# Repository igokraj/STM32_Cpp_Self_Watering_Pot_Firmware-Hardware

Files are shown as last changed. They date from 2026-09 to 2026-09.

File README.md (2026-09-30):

# Self Watering Pot

Projekt zakładał stworzenie automatycznej, samopodlewającej się doniczki na mikrokontrolerze STM32F446RE. Firmware jest napisany w C++. System pilnuje wilgotności gleby i sam włącza pompkę, kiedy gleba robi się za sucha. Da się też wymusić podlewanie ręcznie, a system ma kilka zabezpieczeń na wypadek, gdyby coś poszło nie tak (zaklinowana pompa, uszkodzony czujnik, zawieszony program, pusty pojemnik na wodę).

Do obsługi tego systemu spokojnie można by było użyć mikrokontrolera o mniejszej wydajności, liczbie pinów, pamięci..., jednak ze względu na to, że fizycznie do testowania posiadam jedynie NUCLEO-F446RE, to również na płytce PCB użyłem tego mikrokontrolera dla ujednolicenia projektu. Poniżej zamieszczam zdjęcia prototypu na płytce stykowej (jako zamiennik MOSFETa użyłem diody, symulując jego włączanie/wyłączanie, oraz jako czujnika wilgotności używam ręcznego potencjometru, a do czujnika poziomu wody po prostu kabla, który może być wpięty lub wypięty).

This project set out to build an automatic, self-watering plant pot based on the STM32F446RE microcontroller. The firmware is written in C++. The system keeps an eye on soil moisture and turns the pump on by itself once the soil gets too dry. Watering can also be forced manually, and the system has a few safeguards in case something goes wrong (a stuck pump, a broken sensor, a hung program, an empty water container).

This system would honestly run fine on a much smaller microcontroller which would have a less performance, fewer pins, less memory, but since the only board I physically had for testing was a NUCLEO-F446RE, I used the same chip on the PCB too, just to keep the project consistent. Below are photos of the prototype on a breadboard (I used an LED as a stand-in for the MOSFET, to simulate it switching on/off, a regular potentiometer as a stand-in for the moisture sensor, and for the water level sensor just a loose wire that can be plugged in or pulled out).

## Photos

**Breadboard prototype**
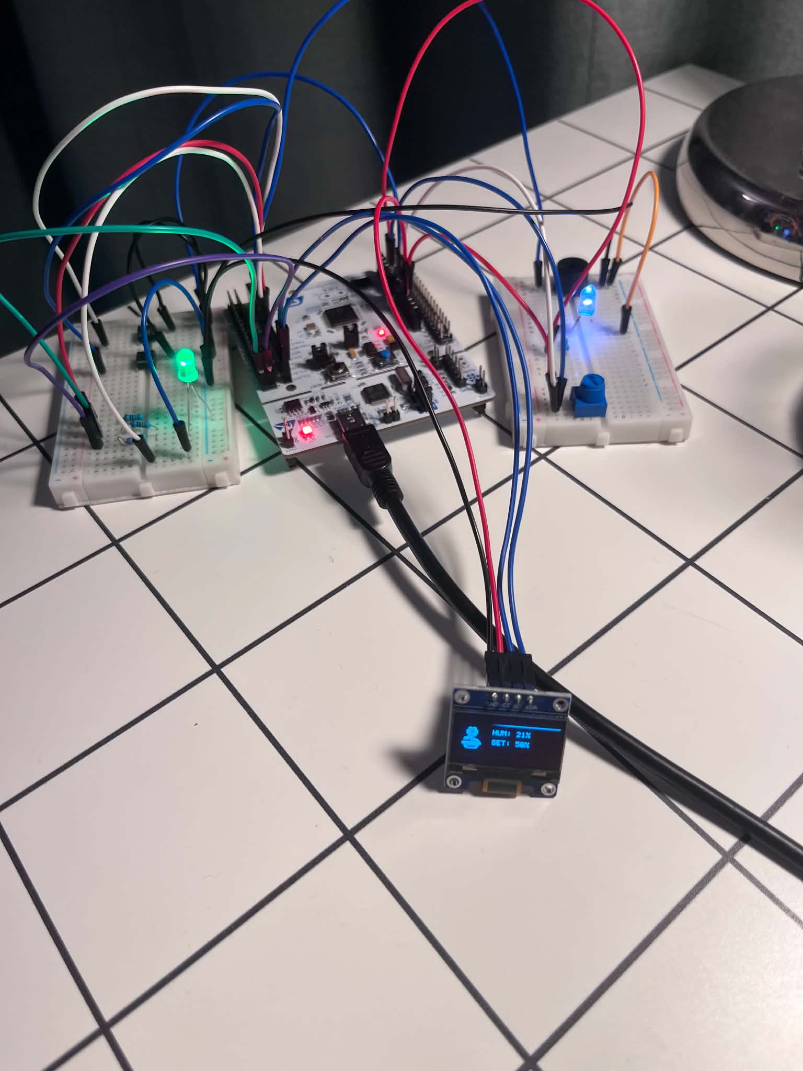
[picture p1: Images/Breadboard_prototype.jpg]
Breadboard prototype


**Schematic**
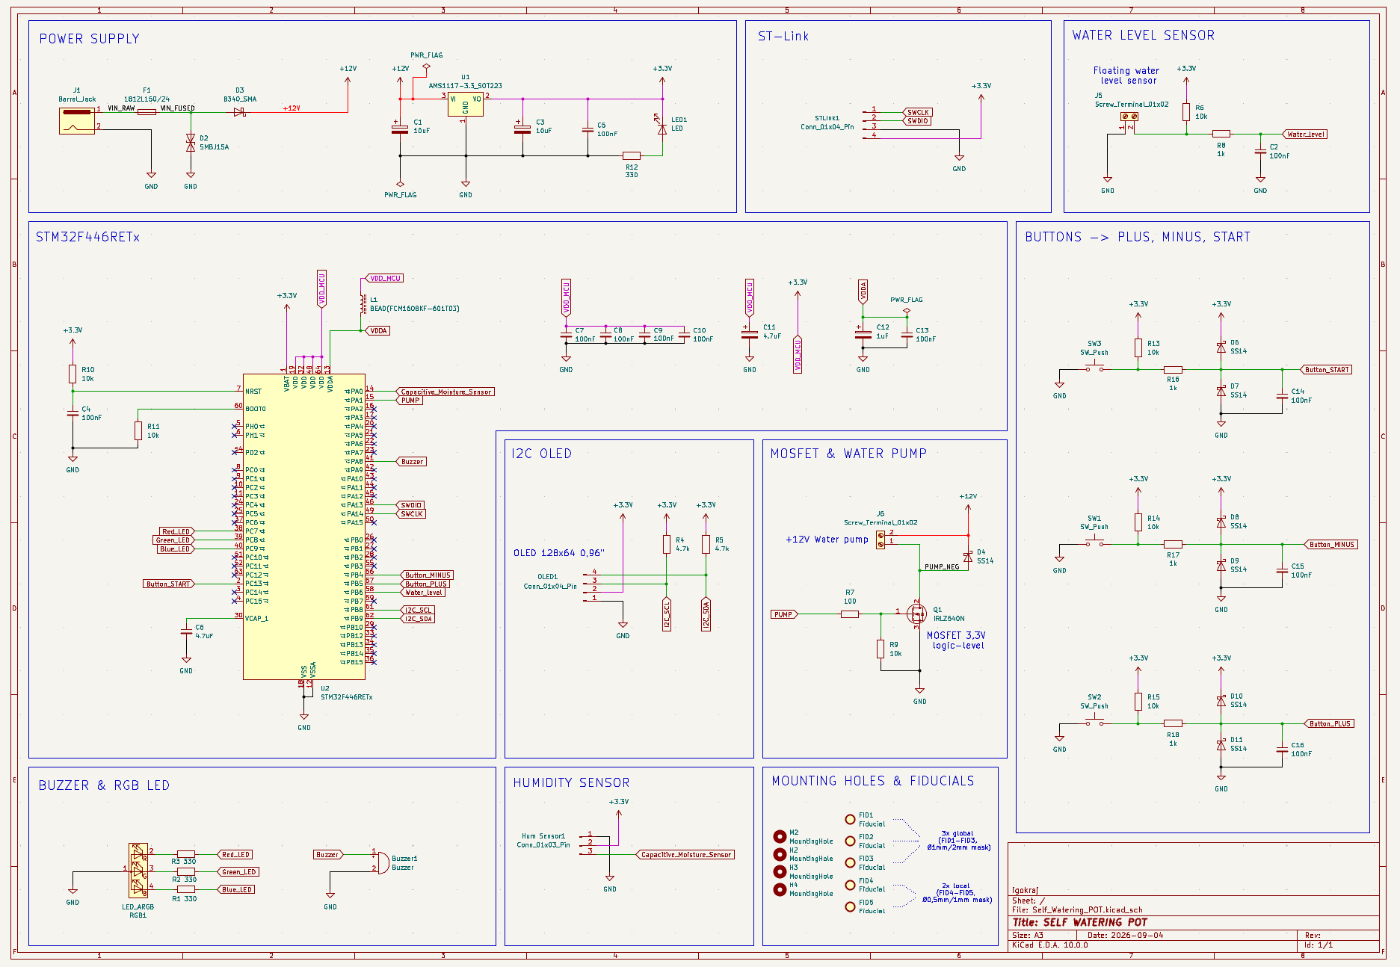
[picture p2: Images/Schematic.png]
Schematic


**PCB layout and 3D render**

<p align="center">
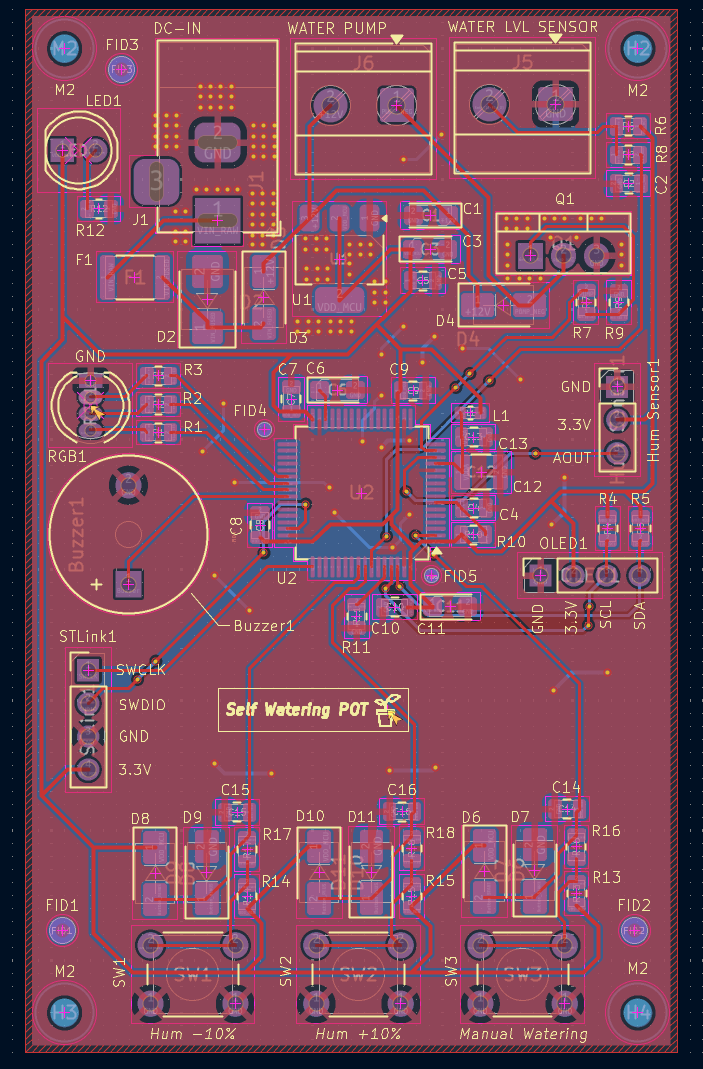
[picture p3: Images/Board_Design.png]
  
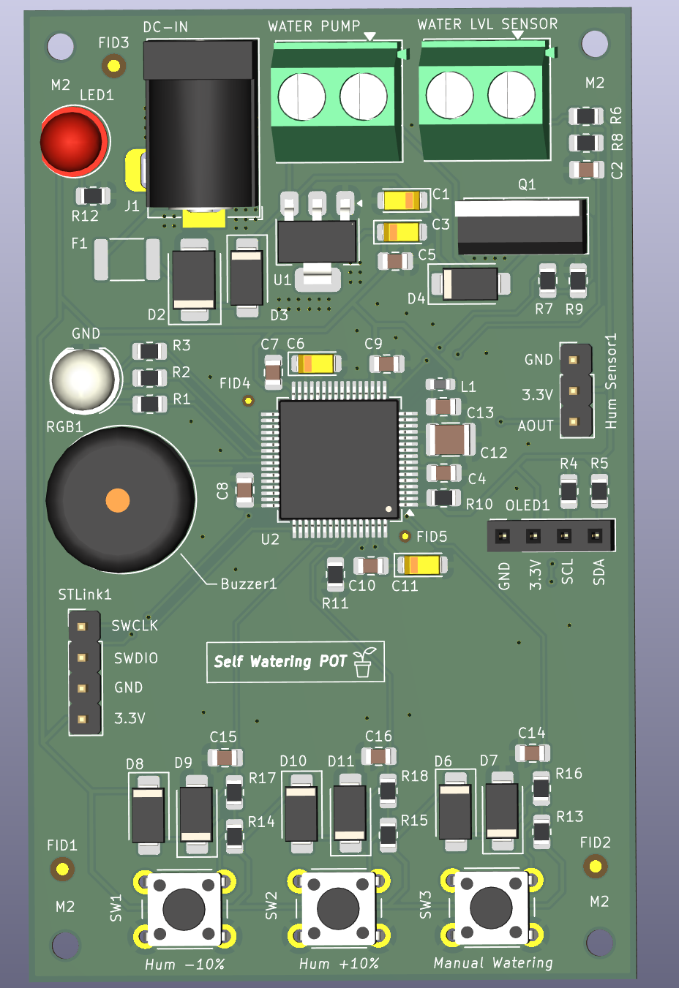
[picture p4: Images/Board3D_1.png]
  
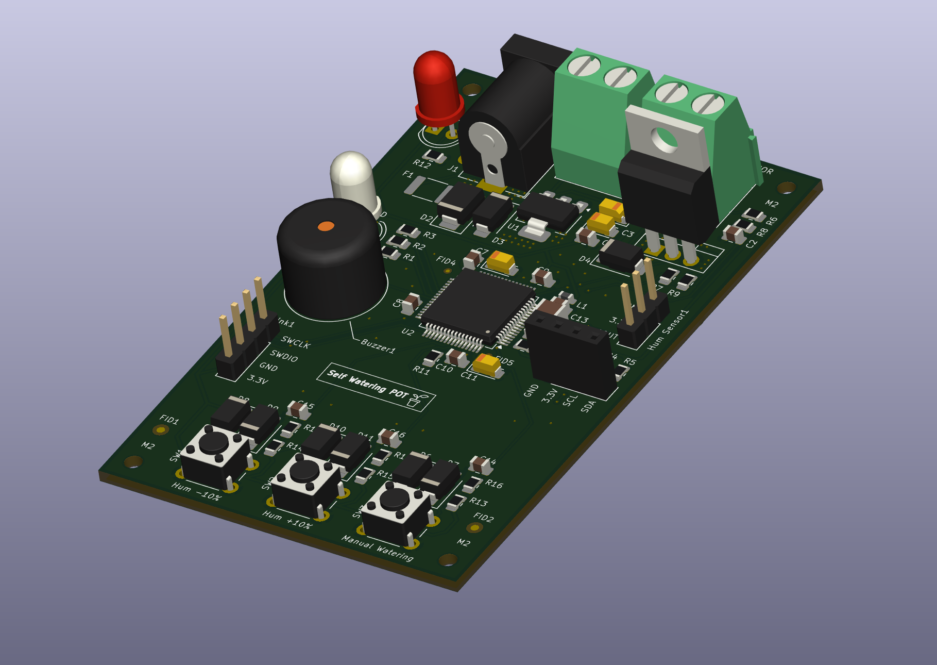
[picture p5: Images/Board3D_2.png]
  
</p>

## How it works

The system has four states: **Waiting**, **Watering**, **EmptyContainer** (no water in the tank), and **Error**.

In the main loop, the program:

1. reads the water level sensor (float switch),
2. handles the Plus/Minus buttons (adjusts the target humidity by 10% per press, with auto-repeat while held) and the manual start button,
3. reads the soil moisture sensor and converts it to a percentage, checking along the way whether the reading looks like a broken/disconnected sensor,
4. decides the state based on that — with priority: pump fault > broken sensor > empty tank > humidity threshold,
5. drives the LEDs, pump, and buzzer, and shows everything on the OLED screen.

Watering kicks in once humidity drops noticeably (by 15 percentage points). If the pump runs continuously for more than 15 seconds, the system treats it as a fault, shuts the pump off for good, and requires a manual reset via the Start button — the buzzer beeps 3 times during this, repeating once a minute.

Holding the Manual Start button forces watering regardless of what the sensor reads.

## Peripherals / electronics

- **STM32F446RETx** — microcontroller
- **Soil moisture sensor** (capacitive) — ADC input
- **Water level sensor** (float switch) — a plain switch
- **3× buttons** — Manual Start, Plus, Minus
- **RGB LED** — indicates system state by color
- **Buzzer** — audible alarm on error
- **Water pump** driven by a MOSFET (IRLZ540N)
- **128×64 OLED display** (SSD1306) over I2C
- **AMS1117-3.3** — 3.3V voltage regulator
- Power connector (barrel jack) with a fuse and overvoltage protection
- SWD connector (ST-Link) for programming/debugging

## BOM (short version)

| Reference | Component | Qty |
| --- | --- | --- |
| U2 | STM32F446RETx | 1 |
| U1 | AMS1117-3.3 (3.3V regulator) | 1 |
| Q1 | IRLZ540N (MOSFET, pump switch) | 1 |
| RGB1 | RGB LED | 1 |
| LED1 | LED (status) | 1 |
| Buzzer1 | Buzzer | 1 |
| SW1–SW3 | Buttons (Start/Plus/Minus) | 3 |
| J1 | Power jack (barrel jack) | 1 |
| J5, J6 | Screw terminals (pump, external power) | 2 |
| Hum Sensor1 | Moisture sensor connector | 1 |
| OLED1 | OLED display connector | 1 |
| STLink1 | Programmer connector | 1 |
| F1 | Fuse | 1 |
| D2 | TVS diode (overvoltage protection) | 1 |
| D3, D4, D6–D11  | Schottky diodes | 8 |
| L1 | Ferrite bead (power filtering) | 1 |
| R, C | Resistors and capacitors (filtering, pull-up/down, debounce circuits) | ~30 |

The full list (with LCSC part numbers) is in `hardware/Self_Watering_POT/BOM.xlsx` and `All_BOM.xlsx`.

## Firmware

The code is written in **C++** (built on top of the C code generated by STM32CubeMX/HAL). The pot's state logic, debounced button handling, OLED display, and buzzer are written as separate classes/modules — the rest (ADC, timer, GPIO, watchdog) is the generated HAL layer.

## Repo structure

- `firmware/` — CMake project with the STM32 sources
- `hardware/` — KiCad schematic and PCB, production files (Gerbers), BOM
- `Images/` — project photos and renders

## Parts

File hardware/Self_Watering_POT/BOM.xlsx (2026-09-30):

Reference | Qty | Value | MPN | Footprint
C1 | 1 | 10uF 25V | C2158829 | Capacitor_Tantalum_SMD:CP_EIA-3216-18_Kemet-A
C3 | 1 | 10uF | C7171 | Capacitor_Tantalum_SMD:CP_EIA-3216-18_Kemet-A
C2,C4,C5,C7,C8,C9,C10,C13,C14,C15,C16 | 11 | 100nF | C49678 | Capacitor_SMD:C_0805_2012Metric
C6,C11 | 2 | 4.7uF | C11369 | Capacitor_Tantalum_SMD:CP_EIA-3216-18_Kemet-A
C12 | 1 | 1uF | C382212 | Capacitor_SMD:C_1210_3225Metric
D2 | 1 | SMBJ15A | C83846 (https://www.lcsc.com/product-detail/C83846.html?s_z=n_q_SMBJ15A) | Diode_SMD:D_SMB
D3 | 1 | B340_SMA | C64982 | Diode_SMD:D_SMA
D4,D6,D7,D8,D9,D10,D11 | 7 | SS14 | C2480 | Diode_SMD:D_SMA
F1 | 1 | 1812L150/24 | C49318453 | Fuse:Fuse_1812_4532Metric
L1 | 1 | BEAD(FCM1608KF-601T03) | C141723 | Inductor_SMD:L_0603_1608Metric
R1,R2,R3,R12 | 4 | 330 | C17630 | Resistor_SMD:R_0805_2012Metric
R4,R5 | 2 | 4.7k | C17673 | Resistor_SMD:R_0805_2012Metric
R6,R9,R10,R11,R13,R14,R15 | 7 | 10k | C17414 | Resistor_SMD:R_0805_2012Metric
R7 | 1 | 100 | C17408 | Resistor_SMD:R_0805_2012Metric
R8,R16,R17,R18 | 4 | 1k | C17513 | Resistor_SMD:R_0805_2012Metric
U1 | 1 | AMS1117-3.3_SOT223 | C6186 (https://www.lcsc.com/product-detail/C6186.html?s_z=n_q_p_AMS1117-3.3_SOT223) | Package_TO_SOT_SMD:SOT-223-3_TabPin2
U2 | 1 | STM32F446RETx | C69336 (https://www.lcsc.com/product-detail/C69336.html?s_z=s_p_STM32F446RET6) | Package_QFP:LQFP-64_10x10mm_P0.5mm

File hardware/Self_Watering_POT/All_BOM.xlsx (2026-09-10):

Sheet: BOM (2)
Reference | Qty | Value | DNP | Exclude from BOM | Exclude from Board | Footprint | Datasheet
Buzzer1 | 1 | Buzzer |  |  |  | Buzzer_Beeper:Buzzer_12x9.5RM7.6
C1,C3 | 2 | 10uF |  |  |  | Capacitor_Tantalum_SMD:CP_EIA-3216-18_Kemet-A
C2,C4,C5,C7,C8,C9,C10,C13,C14,C15,C16 | 11 | 100nF |  |  |  | Capacitor_SMD:C_0805_2012Metric
C6,C11 | 2 | 4.7uF |  |  |  | Capacitor_Tantalum_SMD:CP_EIA-3216-18_Kemet-A
C12 | 1 | 1uF |  |  |  | Capacitor_SMD:C_1210_3225Metric
D2 | 1 | SMBJ15A |  |  |  | Diode_SMD:D_SMB
D3 | 1 | B340_SMA |  |  |  | Diode_SMD:D_SMA
D4,D6,D7,D8,D9,D10,D11 | 7 | SS14 |  |  |  | Diode_SMD:D_SMA
F1 | 1 | 1812L150/24 |  |  |  | Fuse:Fuse_1812_4532Metric
Hum Sensor1 | 1 | Conn_01x03_Pin |  |  |  | Connector_PinHeader_2.54mm:PinHeader_1x03_P2.54mm_Vertical
J1 | 1 | Barrel_Jack |  |  |  | Connector_BarrelJack:BarrelJack_Horizontal
J5,J6 | 2 | Screw_Terminal_01x02 |  |  |  | TerminalBlock_Phoenix:TerminalBlock_Phoenix_MKDS-1,5-2-5.08_1x02_P5.08mm_Horizontal
L1 | 1 | BEAD(FCM1608KF-601T03) |  |  |  | Inductor_SMD:L_0603_1608Metric
LED1 | 1 | LED |  |  |  | LED_THT:LED_D5.0mm
OLED1 | 1 | Conn_01x04_Pin |  |  |  | Connector_PinSocket_2.54mm:PinSocket_1x04_P2.54mm_Vertical
Q1 | 1 | IRLZ540N |  |  |  | Package_TO_SOT_THT:TO-220-3_Vertical
R1,R2,R3,R12 | 4 | 330 |  |  |  | Resistor_SMD:R_0805_2012Metric
R4,R5 | 2 | 4.7k |  |  |  | Resistor_SMD:R_0805_2012Metric
R6,R9,R10,R11,R13,R14,R15 | 7 | 10k |  |  |  | Resistor_SMD:R_0805_2012Metric
R7 | 1 | 100 |  |  |  | Resistor_SMD:R_0805_2012Metric
R8,R16,R17,R18 | 4 | 1k |  |  |  | Resistor_SMD:R_0805_2012Metric
RGB1 | 1 | LED_ARGB |  |  |  | LED_THT:LED_D5.0mm-4_RGB
STLink1 | 1 | Conn_01x04_Pin |  |  |  | Connector_PinHeader_2.54mm:PinHeader_1x04_P2.54mm_Vertical
SW1,SW2,SW3 | 3 | SW_Push |  |  |  | Button_Switch_THT:SW_PUSH_6mm
U1 | 1 | AMS1117-3.3_SOT223 |  |  |  | Package_TO_SOT_SMD:SOT-223-3_TabPin2 | http://www.advanced-monolithic.com/pdf/ds1117.pdf
U2 | 1 | STM32F446RETx |  |  |  | Package_QFP:LQFP-64_10x10mm_P0.5mm | https://www.st.com/resource/en/datasheet/stm32f446re.pdf

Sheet: Arkusz1
Reference | Qty | Value | MPN | Footprint
Buzzer1 | 1 | Buzzer |  | Buzzer_Beeper:Buzzer_12x9.5RM7.6
C1,C3 | 2 | 10uF | C7171 | Capacitor_Tantalum_SMD:CP_EIA-3216-18_Kemet-A
C2,C4,C5,C7,C8,C9,C10,C13,C14,C15,C16 | 11 | 100nF | C1591 | Capacitor_SMD:C_0805_2012Metric
C6,C11 | 2 | 4.7uF | C11369 | Capacitor_Tantalum_SMD:CP_EIA-3216-18_Kemet-A
C12 | 1 | 1uF | C382212 | Capacitor_SMD:C_1210_3225Metric
D2 | 1 | SMBJ15A | C83846 (https://www.lcsc.com/product-detail/C83846.html?s_z=n_q_SMBJ15A) | Diode_SMD:D_SMB
D3 | 1 | B340_SMA | C388236 | Diode_SMD:D_SMA
D4,D6,D7,D8,D9,D10,D11 | 7 | SS14 | C2480 | Diode_SMD:D_SMA
F1 | 1 | 1812L150/24 | C49318453 | Fuse:Fuse_1812_4532Metric
Hum Sensor1 | 1 | Conn_01x03_Pin |  | Connector_PinHeader_2.54mm:PinHeader_1x03_P2.54mm_Vertical
J1 | 1 | Barrel_Jack |  | Connector_BarrelJack:BarrelJack_Horizontal
J5,J6 | 2 | Screw_Terminal_01x02 |  | TerminalBlock_Phoenix:TerminalBlock_Phoenix_MKDS-1,5-2-5.08_1x02_P5.08mm_Horizontal
L1 | 1 | BEAD(FCM1608KF-601T03) | C141723 | Inductor_SMD:L_0603_1608Metric
LED1 | 1 | LED |  | LED_THT:LED_D5.0mm
OLED1 | 1 | Conn_01x04_Pin |  | Connector_PinSocket_2.54mm:PinSocket_1x04_P2.54mm_Vertical
Q1 | 1 | IRLZ540N |  | Package_TO_SOT_THT:TO-220-3_Vertical
R1,R2,R3,R12 | 4 | 330 | C17630 | Resistor_SMD:R_0805_2012Metric
R4,R5 | 2 | 4.7k | C17673 | Resistor_SMD:R_0805_2012Metric
R6,R9,R10,R11,R13,R14,R15 | 7 | 10k | C17414 | Resistor_SMD:R_0805_2012Metric
R7 | 1 | 100 | C17408 | Resistor_SMD:R_0805_2012Metric
R8,R16,R17,R18 | 4 | 1k | C17513 | Resistor_SMD:R_0805_2012Metric
RGB1 | 1 | LED_ARGB |  | LED_THT:LED_D5.0mm-4_RGB
STLink1 | 1 | Conn_01x04_Pin |  | Connector_PinHeader_2.54mm:PinHeader_1x04_P2.54mm_Vertical
SW1,SW2,SW3 | 3 | SW_Push |  | Button_Switch_THT:SW_PUSH_6mm
U1 | 1 | AMS1117-3.3_SOT223 | C6186 (https://www.lcsc.com/product-detail/C6186.html?s_z=n_q_p_AMS1117-3.3_SOT223) | Package_TO_SOT_SMD:SOT-223-3_TabPin2
U2 | 1 | STM32F446RETx | C69336 (https://www.lcsc.com/product-detail/C69336.html?s_z=s_p_STM32F446RET6) | Package_QFP:LQFP-64_10x10mm_P0.5mm

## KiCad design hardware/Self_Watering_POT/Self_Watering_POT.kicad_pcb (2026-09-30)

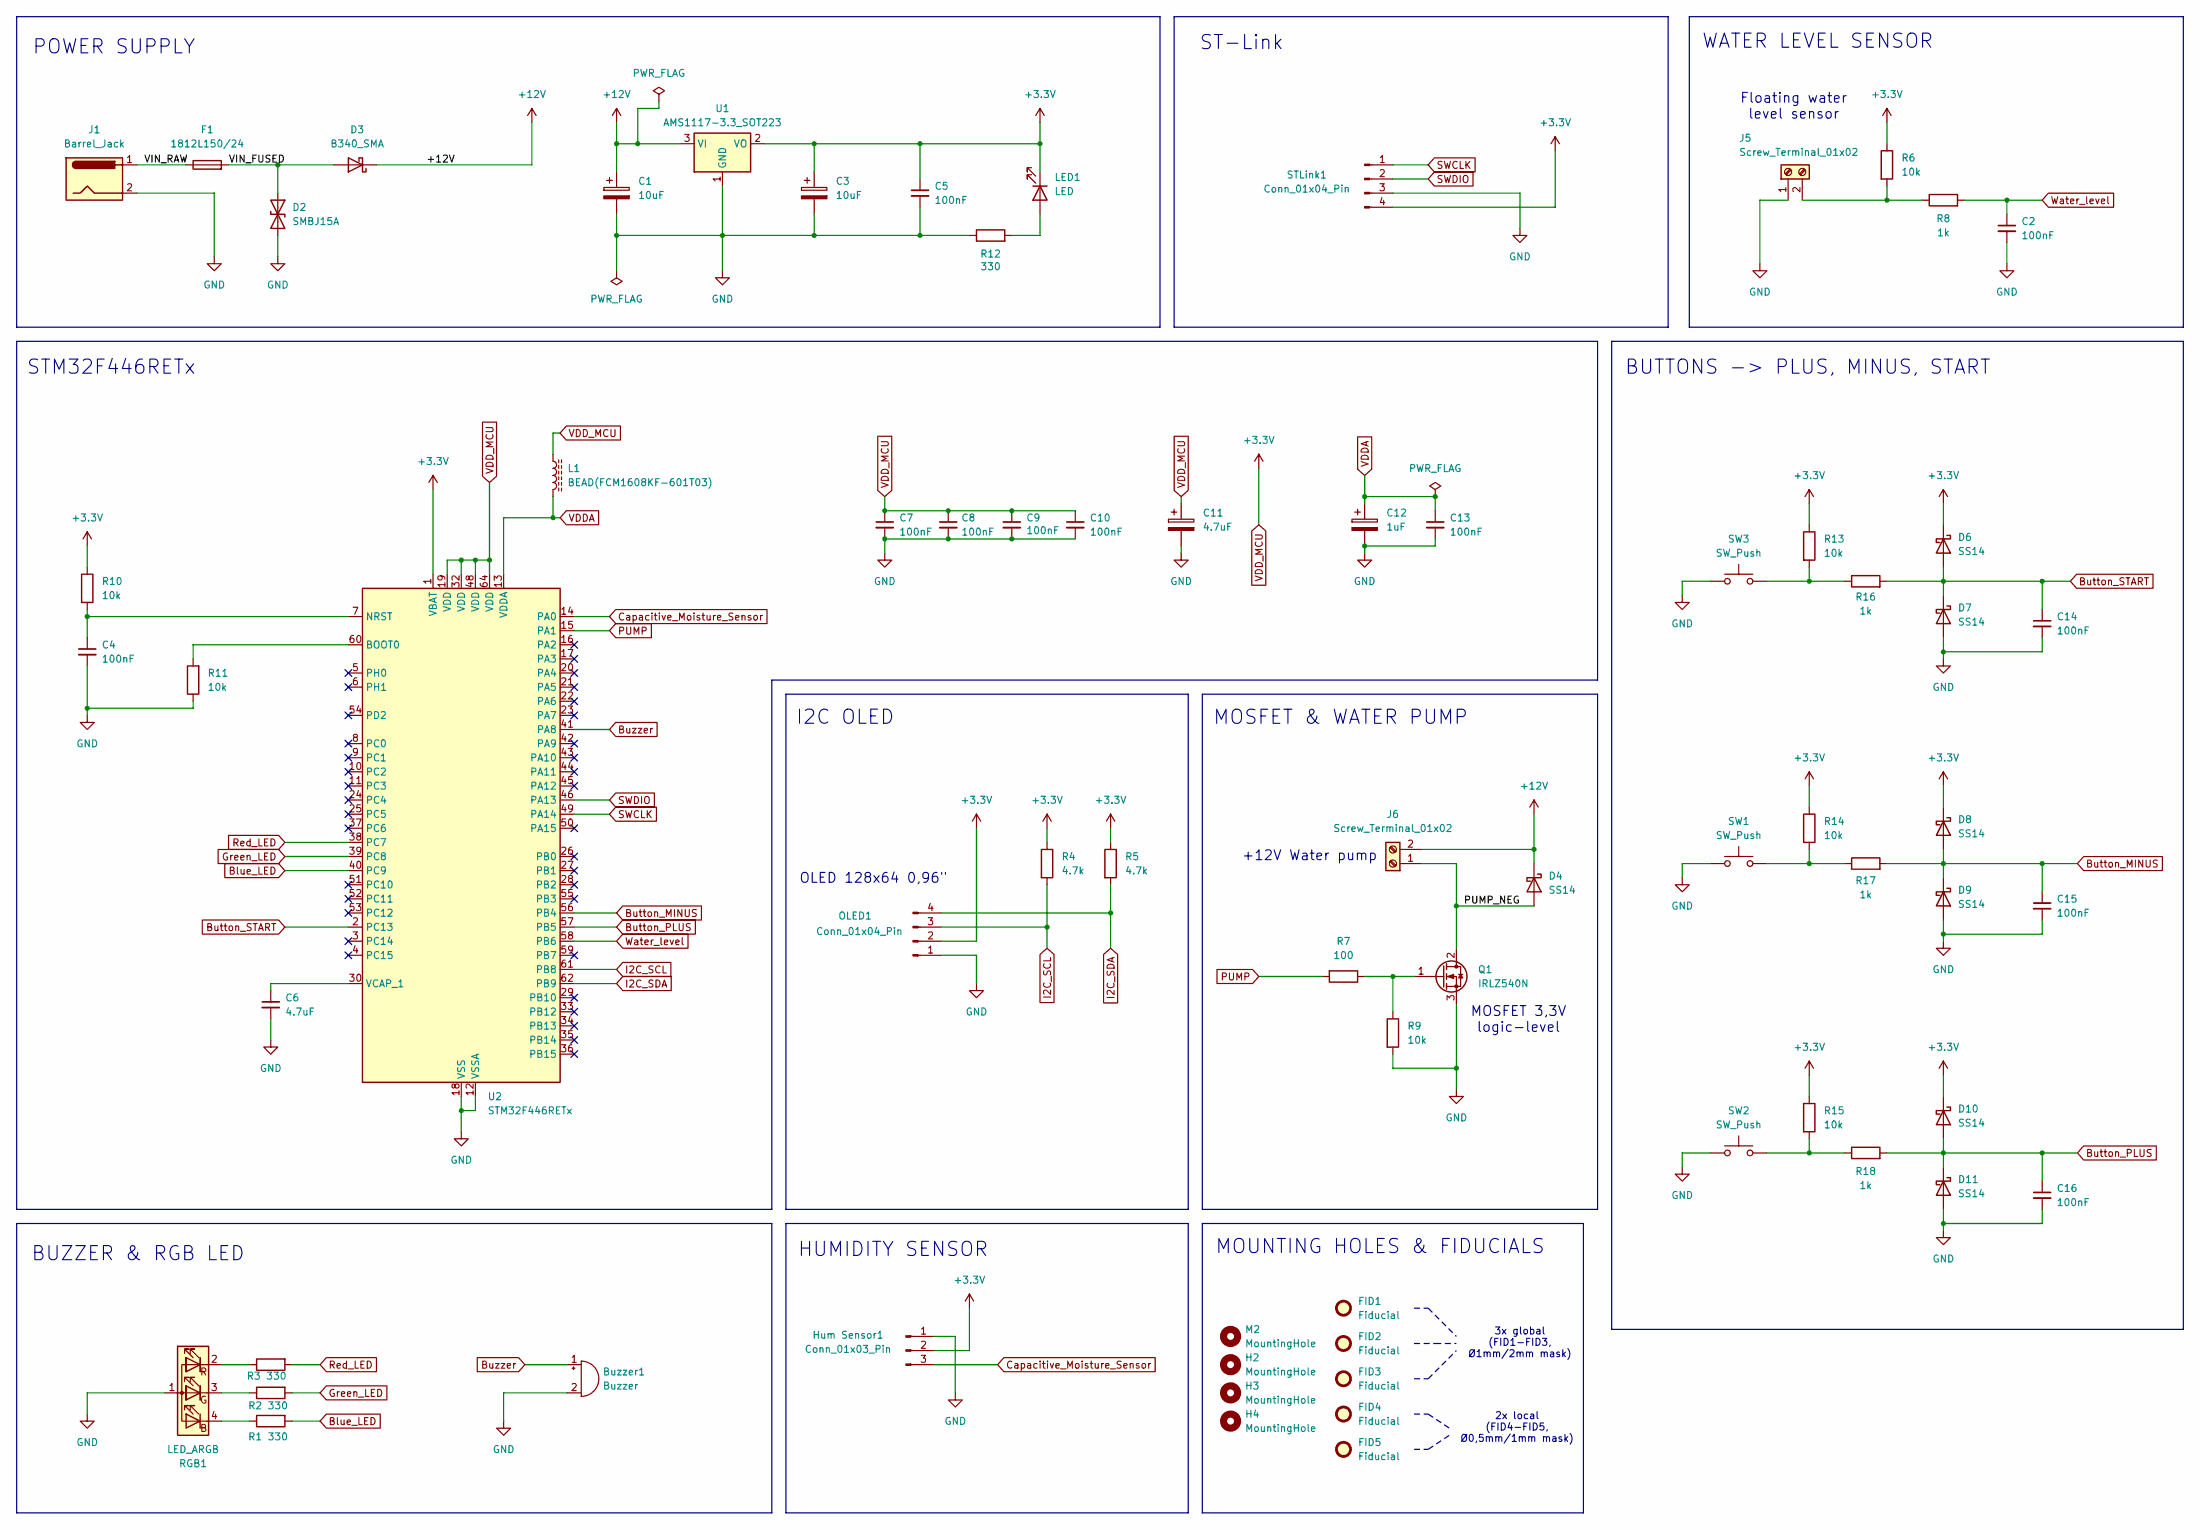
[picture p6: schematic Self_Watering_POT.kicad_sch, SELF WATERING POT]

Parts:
Buzzer1: Buzzer; Buzzer_12x9.5RM7.6
C1, C3: 10uF; CP_EIA-3216-18_Kemet-A
C2, C4, C5, C7, C8, C9, C10, C13, C14, C15, C16: 100nF; C_0805_2012Metric
C6, C11: 4.7uF; CP_EIA-3216-18_Kemet-A
C12: 1uF; C_1210_3225Metric
D2: SMBJ15A; D_SMB
D3: B340_SMA; D_SMA
D4, D6, D7, D8, D9, D10, D11: SS14; D_SMA
F1: 1812L150/24; Fuse_1812_4532Metric
FID1, FID2, FID3: Fiducial; Fiducial_1mm_Mask2mm
FID4, FID5: Fiducial; Fiducial_0.5mm_Mask1mm
H2, H3, H4: MountingHole; MountingHole_2.2mm_M2
Hum Sensor1: Conn_01x03_Pin; PinHeader_1x03_P2.54mm_Vertical
J1: Barrel_Jack; BarrelJack_Horizontal
J5, J6: Screw_Terminal_01x02; TerminalBlock_Phoenix_MKDS-1,5-2-5.08_1x02_P5.08mm_Horizont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
L1: BEAD(FCM1608KF-601T03); L_0603_1608Metric
LED1: LED; LED_D5.0mm
M2: MountingHole; MountingHole_2.2mm_M2
OLED1: Conn_01x04_Pin; PinSocket_1x04_P2.54mm_Vertical
Q1: IRLZ540N; TO-220-3_Vertical
R1, R2, R3, R12: 330; R_0805_2012Metric
R4, R5: 4.7k; R_0805_2012Metric
R6, R9, R10, R11, R13, R14, R15: 10k; R_0805_2012Metric
R7: 100; R_0805_2012Metric
R8, R16, R17, R18: 1k; R_0805_2012Metric
RGB1: LED_ARGB; LED_D5.0mm-4_RGB
STLink1: Conn_01x04_Pin; PinHeader_1x04_P2.54mm_Vertical
SW1, SW2, SW3: SW_Push; SW_PUSH_6mm
U1: AMS1117-3.3_SOT223; SOT-223-3_TabPin2
U2: STM32F446RETx; LQFP-64_10x10mm_P0.5mm

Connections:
+12V: C1.1, D3.1 (K), D4.1 (K), J6.2, U1.3 (VI)
/PUMP_NEG: D4.2 (A), J6.1, Q1.2 (D)
/VIN_FUSED: D2.1 (A1), D3.2 (A), F1.2
/VIN_RAW: F1.1, J1.1
Blue_LED: R1.2, U2.40 (PC9)
Button_MINUS: C15.1, D8.2 (A), D9.1 (K), R17.2, U2.56 (PB4)
Button_PLUS: C16.1, D10.2 (A), D11.1 (K), R18.2, U2.57 (PB5)
Button_START: C14.1, D6.2 (A), D7.1 (K), R16.2, U2.2 (PC13)
Buzzer: Buzzer1.1 (+), U2.41 (PA8)
Capacitive_Moisture_Sensor: Hum Sensor1.3, U2.14 (PA0)
GND: Buzzer1.2 (-), C1.2, C2.2, C3.2, C4.2, C5.2, C6.2, C7.2, C8.2, C9.2, C10.2, C11.2, C12.2, C13.2, C14.2, C15.2, C16.2, D2.2 (A2), D7.2 (A), D9.2 (A), D11.2 (A), Hum Sensor1.1, J1.2, J5.1, OLED1.1, Q1.3 (S), R9.2, R11.1, R12.1, RGB1.1 (A), STLink1.3, SW1.1, SW2.1, SW3.1, U1.1 (GND), U2.12 (VSSA), U2.18 (VSS), U2.31 (VSS), U2.47 (VSS), U2.63 (VSS)
Green_LED: R2.2, U2.39 (PC8)
I2C_SCL: OLED1.3, R4.2, U2.61 (PB8)
I2C_SDA: OLED1.4, R5.2, U2.62 (PB9)
unnamed: J5.2, R6.2, R8.1
unnamed: LED1.2 (A), R12.2
unnamed: Q1.1 (G), R7.1, R9.1
unnamed: R13.2, R16.1, SW3.2
unnamed: R14.2, R17.1, SW1.2
unnamed: R15.2, R18.1, SW2.2
unnamed: R1.1, RGB1.4 (BK)
unnamed: R2.1, RGB1.3 (GK)
unnamed: R3.1, RGB1.2 (RK)
unnamed: R11.2, U2.60 (BOOT0)
unnamed: C4.1, R10.2, U2.7 (NRST)
unnamed: C6.1, U2.30 (VCAP_1)
PUMP: R7.2, U2.15 (PA1)
Red_LED: R3.2, U2.38 (PC7)
SWCLK: STLink1.1, U2.49 (PA14)
SWDIO: STLink1.2, U2.46 (PA13)
VDDA: C12.1, C13.1, L1.2, U2.13 (VDDA)
VDD_MCU: C3.1, C5.1, C7.1, C8.1, C9.1, C10.1, C11.1, D6.1 (K), D8.1 (K), D10.1 (K), Hum Sensor1.2, L1.1, LED1.1 (K), OLED1.2, R4.1, R5.1, R6.1, R10.1, R13.1, R14.1, R15.1, STLink1.4, U1.2 (VO), U2.1 (VBAT), U2.19 (VDD), U2.32 (VDD), U2.48 (VDD), U2.64 (VDD)
Water_level: C2.1, R8.2, U2.58 (PB6)

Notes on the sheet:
+12V Water pump
2x local (FID4-FID5, Ø0,5mm/1mm mask)
MOSFET 3,3V logic-level
OLED 128x64 0,96"
BUZZER & RGB LED
BUTTONS -> PLUS, MINUS, START
I2C OLED
MOUNTING HOLES & FIDUCIALS
Floating water level sensor
POWER SUPPLY
STM32F446RETx
MOSFET & WATER PUMP
HUMIDITY SENSOR
WATER LEVEL SENSOR
ST-Link
3x global (FID1-FID3, Ø1mm/2mm mask)

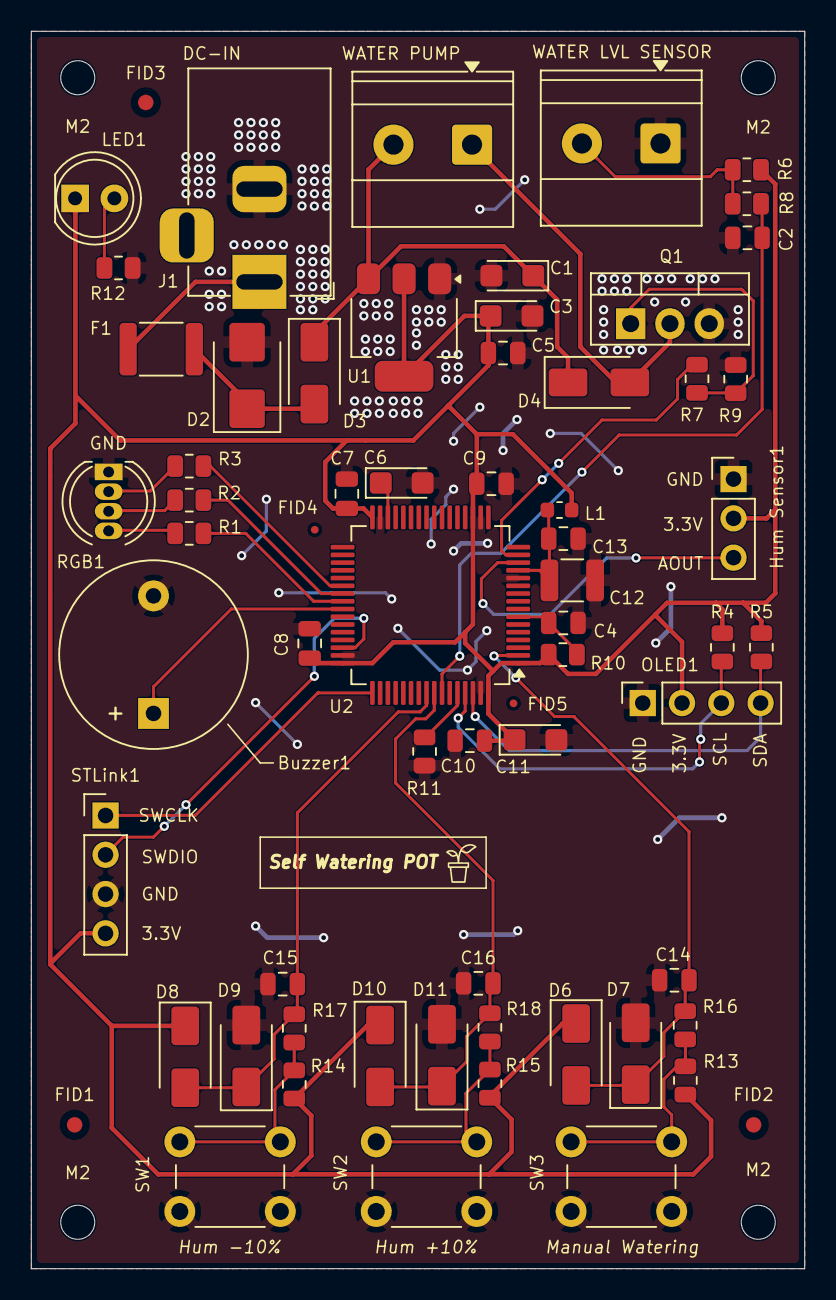
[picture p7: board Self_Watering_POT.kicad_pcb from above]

Board: 2 copper layers, 50.0 x 80.0 mm, 69 parts (0 on the bottom side), 33 nets.

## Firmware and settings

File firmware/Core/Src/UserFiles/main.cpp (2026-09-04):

#include "main.hpp"
#include "iwdg.h"
#include "main.h"
#include "stm32f4xx_hal.h"
#include "adc.h"
#include "buttons.hpp"
#include "display_ui.hpp"
#include "system_status.hpp"
#include "stm32f4xx_hal_gpio.h"
#include "buzzer.hpp"
#include "digital_output.hpp"

// Raw value provided by the capacitive sensor
volatile uint32_t RawHumValue = 0;

// This variable is used for the manual start (it is a flag in the EXTI button handling)
volatile bool ManualButtonStart = 0;

// This variable indicates water level in the container (1 -> container is empty, 0 -> container still has water)
bool ContainerEmpty;

// A healthy, properly connected sensor never sits at either end of the ADC range, so a reading outside these bounds means the sensor failed (broken wire? no power?)
#define SENSOR_RAW_VALUE_MIN 50
#define SENSOR_RAW_VALUE_MAX 4045
bool SensorFailed(uint32_t RawValue) {
    if (RawValue < SENSOR_RAW_VALUE_MIN || RawValue > SENSOR_RAW_VALUE_MAX) {
     return true;
    }
    else {
        return false; 
    }
}

// 0-4095 conversion into 0-100% Humidity value
uint8_t ConvertToPercent(uint32_t rawValue) {
    uint8_t Humidity = (rawValue * 100) / 4095;
    return Humidity;
}


DigitalOutput RedLed(Red_LED_GPIO_Port, Red_LED_Pin);
DigitalOutput GreenLed(Green_LED_GPIO_Port, Green_LED_Pin);
DigitalOutput BlueLed(Blue_LED_GPIO_Port, Blue_LED_Pin);
DigitalOutput Buzzer(Buzzer_Status_GPIO_Port, Buzzer_Status_Pin);
DigitalOutput MOSFET(Pump_on_GPIO_Port, Pump_on_Pin);

void ApplyOutPuts(SystemStatus_t status) {
    switch (status) {
        case SystemStatus_t::Waiting:
            RedLed.off();
            BlueLed.off();
            GreenLed.off();
            MOSFET.off();
            Buzzer.off();
            break;
        case SystemStatus_t::Watering:
            RedLed.off();
            BlueLed.off();
            GreenLed.on();
            MOSFET.on();
            Buzzer.off();
            break;
        case SystemStatus_t::EmptyContainer:
            RedLed.off();
            BlueLed.on();
            GreenLed.off();
            MOSFET.off();
            Buzzer.off();
            break;
        case SystemStatus_t::Error:
            RedLed.on();
            BlueLed.off();
            GreenLed.off();
            MOSFET.off();

            // Beeps a short pattern -> look at BuzzerBeep() to select the exact timing
            BuzzerBeep();
            break;
    }
}

class Pot {

    private:

    uint8_t DesiredHumidity;
    SystemStatus_t SystemStatus = SystemStatus_t::Waiting;

    // static const in the class => one value shared by the whole class, not a per-object copy
    static const uint8_t WateringOffset = 15; // if Humidity <= DesiredHumidity - WateringOffset -> Watering
    static const uint32_t MaxWateringMs = 15000; // maximum continuous watering time, if this limit is exceeded, the system will return an error.
    uint32_t WateringStartTick = 0;

    bool SystemFailed = false;
    
    public: 

    Pot(uint8_t DesiredHumidity) {
        this->DesiredHumidity = DesiredHumidity;
    }

    // ***** GETTERS *****
    // a) Getter for the desired humidity 
    uint8_t GetDesiredHumidity() const { // const method - does not modify the object (const-correctness)
        return DesiredHumidity;
    }
    // b) Getter for the current system status
    SystemStatus_t GetSystemStatus() const { // const method - does not modify the object (const-correctness)
        return SystemStatus;
    }
    // *******************


    /* Decides the next SystemStatus, checked in priority order:
    a latched pump fault (only the Start button can clear it) beats a bad sensor reading, which beats an empty container, which beats the humidity threshold itself. Watering is capped at MaxWateringMs so a stuck sensor cannot leave the pump running forever */
    void UpdateSystem(uint8_t currentHumidity, bool ContainerEmpty, bool SensorFailed, bool ManualButtonStart) {

        if (ManualButtonStart) { 
            Clear_SystemFailed(); 
        }
        if (SystemFailed) {
            SystemStatus = SystemStatus_t::Error;
            return;
        }

        if (SensorFailed) {
                SystemStatus = SystemStatus_t::Error;
                WateringStartTick = 0;
                return;
            }
        if (ContainerEmpty) {
                SystemStatus = SystemStatus_t::EmptyContainer;
                WateringStartTick = 0;
                return;
        }
        bool PlantNeedsWater = (currentHumidity <= DesiredHumidity - WateringOffset || ManualButtonStart);

        if (PlantNeedsWater) {
            if (SystemStatus == SystemStatus_t::Watering) {
                if (HAL_GetTick() - WateringStartTick > MaxWateringMs) {
                    SystemStatus = SystemStatus_t::Error;
                    SystemFailed = true; // pump ran too long - STOP the system
                }
            }
            else {
                WateringStartTick = HAL_GetTick();
                SystemStatus = SystemStatus_t::Watering;
            }
        }
        else {
            SystemStatus = SystemStatus_t::Waiting;
            WateringStartTick = 0;
        }
    }

    // ***** SETTER *****
    void SetDesiredHumidity(uint8_t DesiredHumidity) {
        this->DesiredHumidity = DesiredHumidity;
    }
    // ******************

     void Clear_SystemFailed() {
        SystemFailed = false;
    }
};

   

// Desired humidity set right after start of the system
Pot AloePot(50);


void app_main() {

HAL_IWDG_Refresh(&hiwdg);  // fresh watchdog window - display init takes a moment
DisplayInit();

while (1) {

ContainerEmpty = HAL_GPIO_ReadPin(Water_level_GPIO_Port, Water_level_Pin);

if (btnPlus.Update()) {
    uint8_t newHumidity = AloePot.GetDesiredHumidity() + 10;
    if (newHumidity > 100) {
        newHumidity = 100;
    }
    AloePot.SetDesiredHumidity(newHumidity);
}

if (btnMinus.Update()) {
uint8_t currentHumidity = AloePot.GetDesiredHumidity();
uint8_t newHumidity = (currentHumidity >= 10) ? currentHumidity - 10 : 0;
    AloePot.SetDesiredHumidity(newHumidity);
}

// Why did i use raw variable here? 
// RawHumValue is volatile and can change under an ADC interrupt at any point, so it is snapshotted once here - otherwise ConvertToPercent and SensorFailed could end up judging two different readings within the same decision
uint32_t raw = RawHumValue;
uint8_t humidity = ConvertToPercent(raw);
AloePot.UpdateSystem(humidity, ContainerEmpty, SensorFailed(raw), ManualButtonStart);

ApplyOutPuts(AloePot.GetSystemStatus());

RefreshDisplay(humidity, AloePot.GetDesiredHumidity(), AloePot.GetSystemStatus());

HAL_IWDG_Refresh(&hiwdg); // watchdog only guards against a hung main loop

}


}


// Callback function for ADC start in ISR
void HAL_TIM_PeriodElapsedCallback(TIM_HandleTypeDef *htim)
{
if (htim->Instance == TIM6) {
HAL_ADC_Start_IT(&hadc1);
}

}

// Callback for the humidity measurement in ISR
void HAL_ADC_ConvCpltCallback(ADC_HandleTypeDef *hadc)
{
    if (hadc->Instance == ADC1) {
        RawHumValue = HAL_ADC_GetValue(hadc);
    }
}

// Callback for the Start button EXTI
void HAL_GPIO_EXTI_Callback(uint16_t GPIO_Pin)
{

  if (GPIO_Pin == Start_Button_Pin) {
  ManualButtonStart = !ManualButtonStart;
  }
}

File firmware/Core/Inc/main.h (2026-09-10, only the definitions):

#define Start_Button_Pin GPIO_PIN_13
#define Start_Button_GPIO_Port GPIOC
#define Start_Button_EXTI_IRQn EXTI15_10_IRQn
#define ADC1_Hum_Pin GPIO_PIN_0
#define ADC1_Hum_GPIO_Port GPIOA
#define Pump_on_Pin GPIO_PIN_1
#define Pump_on_GPIO_Port GPIOA
#define USART_TX_Pin GPIO_PIN_2
#define USART_TX_GPIO_Port GPIOA
#define USART_RX_Pin GPIO_PIN_3
#define USART_RX_GPIO_Port GPIOA
#define Red_LED_Pin GPIO_PIN_7
#define Red_LED_GPIO_Port GPIOC
#define Green_LED_Pin GPIO_PIN_8
#define Green_LED_GPIO_Port GPIOC
#define Blue_LED_Pin GPIO_PIN_9
#define Blue_LED_GPIO_Port GPIOC
#define Buzzer_Status_Pin GPIO_PIN_8
#define Buzzer_Status_GPIO_Port GPIOA
#define TMS_Pin GPIO_PIN_13
#define TMS_GPIO_Port GPIOA
#define TCK_Pin GPIO_PIN_14
#define TCK_GPIO_Port GPIOA
#define SWO_Pin GPIO_PIN_3
#define SWO_GPIO_Port GPIOB
#define Button_Minus_Pin GPIO_PIN_4
#define Button_Minus_GPIO_Port GPIOB
#define Button_Plus_Pin GPIO_PIN_5
#define Button_Plus_GPIO_Port GPIOB
#define Water_level_Pin GPIO_PIN_6
#define Water_level_GPIO_Port GPIOB

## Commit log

2026-09-02 Added ADC inicialization and hum measurement in TIM/ADC callback functions
2026-09-02 Added raw ADC value conversion and corrected TIM6 ARR value
    [Self_Watering_Pot.ioc, main.cpp]
2026-09-02 Added button plus/minus handling in C
2026-09-02 Refactored button handling into C++
2026-09-02 Added separate class DigitalOut to handle RGB LED, Buzzer and MOSFTET gate GPIO pins, Added IDQG refresh every ~2ms, Assembled the main while(1) loop, Added Button objects (btnPlus, btnMinus), Implem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
    [Self_Watering_Pot.ioc, buttons.cpp, main.cpp]
2026-09-02 Corrected output handling in ApplyOutPuts funtion
    [main.cpp]
2026-09-03 Added Buzzer.off to the other states of the system so it's no longer stay on forever
    [main.cpp]
2026-09-03 Enhanced output handling in the Error state
    [main.cpp]
2026-09-03 Changed the variable name and the logic of the water level indicating pin
2026-09-03 Changed I2C clock speed and humidity getter type
2026-09-03 Adjust watering condition to trigger when humidity drops below desired level by 15% so the humidity won't go too far outside the expected range
    [main.cpp]
2026-09-03 Fix the watering safety limit and detect a broken sensor
    Until now the 15s watering time limit didn't actually work — once it tripped, the watchdog would reset the board, but the system just came back up in the same state and started watering all over again. Now a fault actually stops the pump for good (needs the Start button to clear it manually), and the watchdog only guards against a hung program instead of getting tangled up with the error logic.
    Also added: detection of a disconnected/broken sensor (reading outside a sane ADC range), and fixed a bug where a single loop pass could end up judging two different sensor readings instead of one
    [buttons.cpp, main.cpp]
2026-09-04 Added new buzzer funcionality and integrated it into main logic, moved DigitalOutput class to the separate file to handle multiple files
    [main.cpp]
2026-09-10 Added KiCAD hardware files and matched firmware pins with component layout on the board
    [All_BOM.xlsx, BOM.xlsx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]
2026-09-30 Corrected MPN in BOM
    [BOM.xlsx]
2026-09-30 Corrected mistakes with PCB board
    [BOM.xlsx, Self_Watering_POT.kicad_pcb, Self_Watering_POT.kicad_sch]
2026-09-30 Update README photos: fix renamed board images and align PCB views in a row
    Corrected Images/ paths after board render filenames changed, and switched
    the PCB layout/3D renders to fixed-height inline images so the two portrait
    screenshots no longer dominate the page with excessive scrolling.

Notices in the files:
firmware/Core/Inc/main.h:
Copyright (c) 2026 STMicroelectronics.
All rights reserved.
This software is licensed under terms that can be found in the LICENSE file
